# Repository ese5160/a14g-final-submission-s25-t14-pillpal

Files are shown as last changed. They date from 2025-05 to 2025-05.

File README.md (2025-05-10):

Review Assignment Due Date (https://classroom.github.com/a/AlBFWSQg)
# a14g-final-submission

    * Team Number: 14
    * Team Name: PillPal
    * Team Members: Urvi Haval & Suhaila Shankar
    * Github Repository URL: https://github.com/ese5160/a14g-final-submission-s25-t14-pillpal
    * Description of test hardware: (development boards, sensors, actuators, laptop + OS, etc) 

## 1. Video Presentation

https://youtu.be/ZBLSTaz6bz8

## 2. Project Summary
### Device Description  
#### What is our device?   
We have designed and implemented an IoT-based pill dispenser that works using a stepper motor and a custom pill dispensing mechanism, triggered by scheduled commands via Node-RED. It uses a servo for accessing the main compartment with the pills and integrates an RFID module for scure access control. It also uses a temperature sensor to ensure that the device is kept in optimal conditions.   

#### Inspiration  
The project was inspired by the DOTS program for Tuberculosis observed in India that mandates a particular dosage of pills without missing even a single dose. Missing doses can lead to reverse effects. Monitoring this is usually very hard and in a few cases, patients tend to overdose or underdose. Apart from being a regular pill dispenser, we had to make sure that only a doctor or a medical health provider has access to where all the pills are stored to ensure medical adherence.  

#### Internet Integration  
The device connects to the Internet via Wi-Fi and uses MQTT to communicate with a Node-RED dashboard, allowing users or caregivers to remotely monitor, trigger and adjust dispensing schedules in real time.  

### Device Functionality  
#### Overview  
Our pill dispenser is designed around the SAMD21 microcontroller that coordinates inputs from sensors and outputs to actuators, while maintaining two-way communication with a remote server via Wi-Fi. The device ensures secure, scheduled pill dispensing, remote monitoring, and user interaction through a Node-RED dashboard.  
**Key components**:  
SENSORS:  
- RFID Reader (PN532) connected over Arduino which authenticates users before allowing access to refill or interact with the device.  
- Button on the PCB (PB23) used for manual override or triggering functions locally.  
- Temperature sensor (BMP388) periodically logs ambient temperature for monitoring pill storage conditions.  
  
ACTUATORS:  
- Stepper motor (controlled via DRV8834 Driver on board) which rotates the upper disc to align with the correct pill slot with the dispensing outlet.  
-  Servo Motor controls the opening and closing of the main lid for loading pills.  
- Buzzer and LED provide alerts for dispensing confirmation or attention signals.  
  
CONNECTIVITY:  
- Wi-Fi Module which enables MQTT communication between the PCB and the Node-RED dashboard.  
- MQTT Topics:  
1. **"pill/status"**: Used to publish pill dispensing events.  
2. **"pill/count"**: Used to publish remaining pill count.  
3. **"debug/ota"**: Used to download OTAFU through the Node-RED UI.  
  
POWER SUPPLY:  
- The stepper and servo motors are powered by an on-board regulated 5V supply using a boost converter.  
- The rest of the peripherals and the microcontroller are powered by a regulated 3V3 supply from the on-board buck converter.  
  
SOFTWARE INTEGRATION:  
- FreeRTOS manages real-time task scheduling for servo control, stepper rotation, temperature sensor reading and MQTT communication, ensuring deterministic and responsive behavior.  
- The CLI Debug interface allows developers to issue test commands via the serial monitor during development and maintenance.  
  
HARDWARE DESIGN:  
- Our custom PCB was designed using *Altium Designer*. It integrates all components on a compact and efficient layout, with properly routed traces for I2C, motor control signals and regulated power distribution. Going with the theme of the project, we also made the PCB to be a 'plus' sign.  
  
#### System Block Diagram  
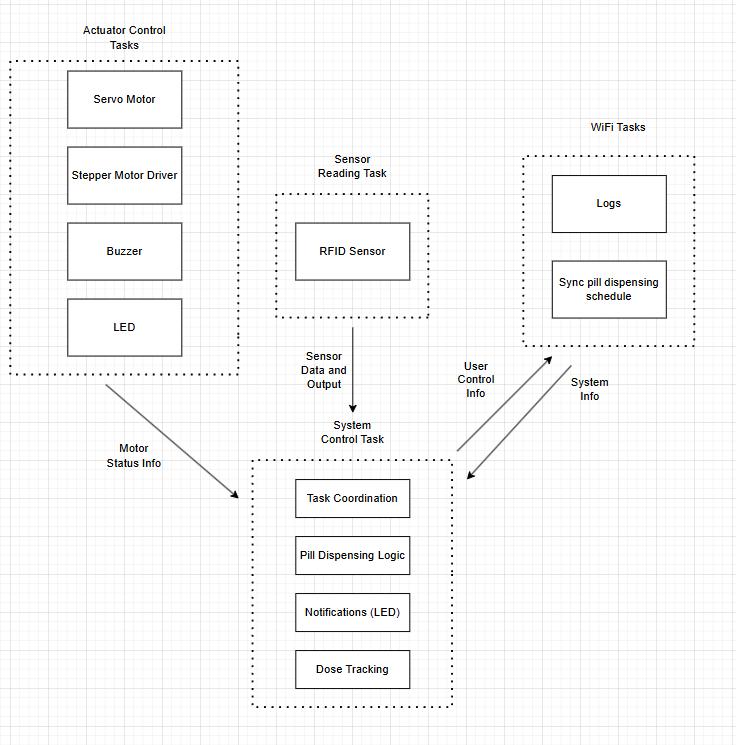
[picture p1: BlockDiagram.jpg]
System Block Diagram

  
### Challenges  
Developing this project involved tackling multiple challenges accross firmware development, hardware debugging and full system integration. Some of the most significant roadblocks and our approaches to resolving them are outlined below.  
  
1. PN532 I2C communication: One of the earliest and most time-consuming challenges in firmware arose during the integration of the PN532 RFID reader via I2C. While writing to the sensor worked reliably using the FreeRTOS-based I2C driver, we consistently missed two packets while reading back from it. We spent quite a lot of time debugging and analyzing on the SALAE Logic Analyzer, tried changing the on-board pull up resistors. Since we were using the breakout board for PN532, the datasheet was not of much help as it was meant for the SOC. The problem was compounded by the lack of thorough documentation or working examples of a minimal I2C-based PN532 driver written in pure C—most open-source implementations either used SPI or were heavily abstracted in C++ (e.g., Adafruit’s Arduino library).  Eventually, in the interest of time and project stability, we decided to offload the RFID functionality to a separate Arduino Nano. This external board successfully communicated with the PN532 using a well-supported library and then forwarded authentication results over UART to the main SAMD21 controller.  

2. Boost Converter Failure: We designed an onboard boost converter circuit using the TPS6123 IC to power certain components from a lower voltage source. However, during early hardware testing, the circuit failed to deliver the expected output voltage. Upon investigation using an electronic load (eload) and multimeter measurements, we discovered that the ground pins on the TPS6123 were inadvertently floating—left electrically unconnected to the board’s main ground plane. To address this, we manually soldered jumper wires to tie the floating ground points to the main ground. Although this initially appeared to resolve the issue, it caused a massive and uncontrolled current draw, ultimately blowing the boost converter. Hence we took the decision to use an external 5V DC supply.  
  
### Prototype Learnings  
Building and testing this prototype provided valuable insights across hardware design, firmware development, and system-level decision-making. Through iterative development and troubleshooting, we identified both best practices and areas for improvement.  
**Key Lessons Learnt:**  
1. While the PN532 RFID module offered robust features, its complexity and lack of C-based I2C documentation slowed our progress significantly. In hindsight, choosing a simpler RFID reader or integrating the module directly onto the PCB instead of using a breakout board would have reduced wiring errors, saved space, and improved stability.  
2. During FreeRTOS integration, we initially underestimated the memory requirements for tasks like Wi-Fi, I2C, and servo control. These tasks, especially when using semaphores and queues, require careful tuning of stack sizes and heap allocation. We learned to regularly monitor uxTaskGetStackHighWaterMark() and adjust configTOTAL_HEAP_SIZE early in development to prevent obscure runtime crashes.  
3. One of the most important takeaways was learning when to stop pursuing a dead-end and shift to a viable workaround. Rather than getting stuck debugging low-level I2C read issues with the PN532, we made the decision to offload the RFID task to a dedicated Arduino. This pivot allowed us to maintain progress and demonstrated the value of modular, flexible architecture in embedded design.  

**What we'd do differently**:  
- Opt for a simpler or more well-documented RFID solution with native MCU support and potentially integrate it directly into the custom PCB.  
- Allocate more time early on for testing task stack sizes and overall heap usage to avoid late-stage integration issues.  
- Prioritize pragmatic engineering and spending less time on unsolved problems and being quicker to adopt alternate paths when necessary.  

### Next steps and takeaways  
#### Next steps to improve the project  
1. **Enhancing the Node-RED dashboard**: The current UI supports basic control, but it can be made far more interactive. Future improvements include adding pill scheduling via a software-based RTC, supporting multiple daily dispensing times, and dynamically updating the remaining pill count. Enhancing the interface with custom CSS would also improve usability and accessibility.  
2. **Simplifying RFID hardware integration**: Instead of relying on a bulky breakout board and an Arduino for RFID handling, future iterations could include a simpler I2C-compatible RFID module (like the SparkFun Qwiic RFID) that can be directly integrated into the main PCB. This reduces wiring complexity, power consumption, and form factor.  
3. **Refining task synchronization and System Integration**: While the prototype runs all subsystems, better task coordination using semaphores better (e.g., signaling between the button, servo, and stepper tasks) would make the system more efficient and deterministic under FreeRTOS. A more structured communication scheme would also reduce the likelihood of task starvation or conflicts.
  
#### What we learned during ESE5160   
Throughout the ESE5160 course, we gained practical and theoretical skills essential to embedded system development.  
1. Firmware Design and RTOS Concepts: We learned how to structure embedded applications using FreeRTOS, manage concurrency using tasks, queues, and semaphores, and debug common issues like stack overflows and heap exhaustion.  
2. Peripheral and Driver Integration: Assignments and lectures taught us how to interface with hardware components such as LEDs, servos, buttons, I2C sensors, and motor drivers through low-level drivers and interrupt-safe communication patterns.  
3. Networking and IoT Protocols: Implementing MQTT and integrating with a cloud-based Node-RED dashboard taught us how to design real-world IoT applications involving secure data exchange and remote control.  
4. System-Level Debugging and Design Thinking: Most importantly, we learned how to debug complex hardware-software interactions and make trade-offs between ideal and practical solutions, especially during our prototype’s challenges.  

### Project Links  
**Link to Node-RED instance:** http://135.119.168.251:1880/ui/#!/1?socketid=zufB0bCCymFWlRAdAAC7  
**Link to PCBA:** https://upenn-eselabs.365.altium.com/designs/8B70E409-2835-43B1-999B-2FA11EA3B7DD#design

## 3. Hardware & Software Requirements  
### Hardware Requirements Validation

| ID | Requirement Description | Status | Validation Method |
|---|---|---|---|
| HR 01 | Project uses the SAMW25 microcontroller module |  Met | Verified via firmware check / chip ID. |
| HR 02 | An RFID reader shall be used for access control. The reader shall authenticate RFID tags at a maximum distance of 5 cm and communicate with the microcontroller via I2C. |  Partially Met | Range tested with ruler. Communication verified via I2C ACK/NACK and tag UID. |
|HR 03 | If the RFID tag matches the reader, the main compartment shall open, which is controlled by a servo motor. | Met | The servo opens and closes the slot for inputting the pills.
| HR 04 | The pill will be dispensed using a carousel design. A rotating disc is aligned with a dispensing chute. The disc rotates using a stepper motor to position the correct slot over the chute at the scheduled time. | Met | Tic-Tac placed for experimenting is dispensed. |
| HR 05 | The device shall include a buzzer for audio notifications. The buzzer shall produce a sound output of at least dB at ? cm and shall be activated for dose alerts. |  Partially Met | Buzzer tested. dB output needs measurement at 10 cm using phone dB meter. |
| HR 06 | A Lithium Ion Cylindrical Battery - 3.7V, 2200mAh shall be used as the power source. The battery shall be parallely connected to a Boost Convert (6V) and a Buck Converter (3.3V). |  Partially Met | Multimeter used to verify 3.3V rail. Performed e-load testing as well. Boost converter however does not work due to DRC errors in the PCB design. Used an external 5V DC supply. |
| HR 07 | The enclosure and carousel dispensing mechanism should be 3D printed. |  Met | Measured dimensions. Lid and mechanism assembled as per spec. |
| HR 08 | The pill dispenser shall use 802.11 b/g/n Wi-Fi for communication with cloud services. |  Met | Verified MQTT communication with Node-RED via serial logs. |
| HR 09 |  An LED shall indicate dose alerts. |  Met | LEDs trigger on stepper motor turning battery logic. |
| HR 10 | A load cell/force sensor should be placed at the end of the dispenser to check if the patient picks up the pill |  Not Met | Was not a mandatory requirement. |

### Software Requirements Validation  
## Software Requirements Validation

| ID | Requirement Description | Status | Validation Method |
|---|---|---|---|
| SRS 01 | A notification shall be sent to the patient when they need to take their medication on Node-RED. |  Met | Verified on Node-RED task. |
| SRS 02 | A reminder notification shall be sent in 5 minutes if the patient has not taken their medication. | Not Met | Future scope |
| SRS 03 | A counter shall keep track of the number of pills left in the dispenser and alert the patient. The counter subtracts the pill amount every time the stepper motor dispenses the pill. |  Met | Decrement logic on stepper task; MQTT alert sent. Verified on Node-RED |
| SRS 04 | A schedule shall be set by the provider to send reminders for taking pills. | Partially Met | Practitioner can set schedule on Node-RED dashboard. Future scope to integrate it with the hardware. |
| SRS 05 | An MQTT broker shall communicate with Node-RED for sending alerts |  Met | Verified with payloads on "pill/alert" and "pill/status" topics. |
| SRS 06 | Node-RED UI dashboard shall displays pill count, status, and connectivity |  Met | Dashboard fields update on MQTT publish from MCU. | 
| SRS 07 | A FreeRTOS task shall read temperature data every 10 seconds and publish it via MQTT |  Met | Temperature task uses vTaskDelay(10000/portTICK_PERIOD_MS). MQTT publish verified on topic "pill/temp". Reading accuracy validated by comparing with ambient temperature. |
| SRS 08 | The system shall run all tasks (dispense, sensor, comms, alerts) concurrently under FreeRTOS |  Partially Met | Tasks are created and run under FreeRTOS. Validation via serial logs and functional testing. However, system occasionally freezes or stops responding, indicating potential stack/heap mismanagement or race condition. Debugging ongoing. |

## 4. Project Photos & Screenshots

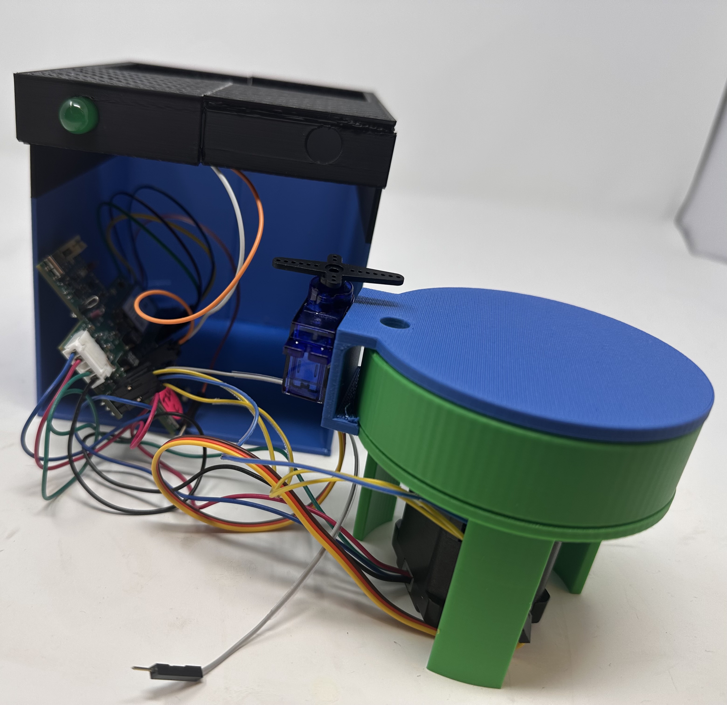
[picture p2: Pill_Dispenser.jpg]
Dispenser


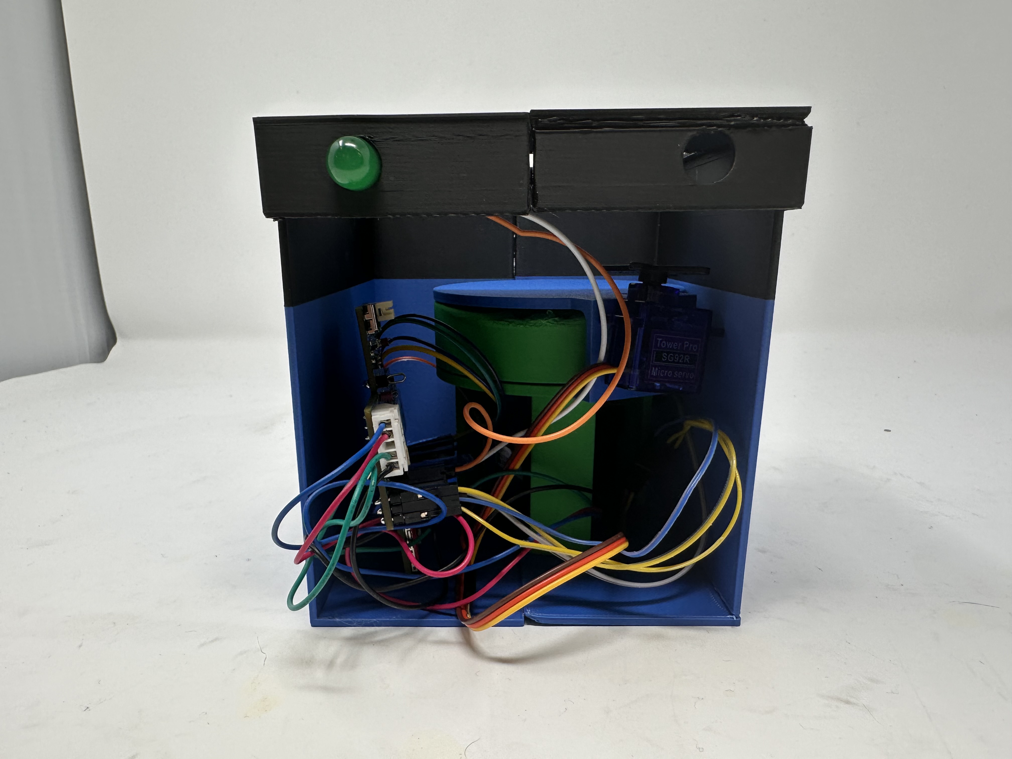
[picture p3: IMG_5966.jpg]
Setup


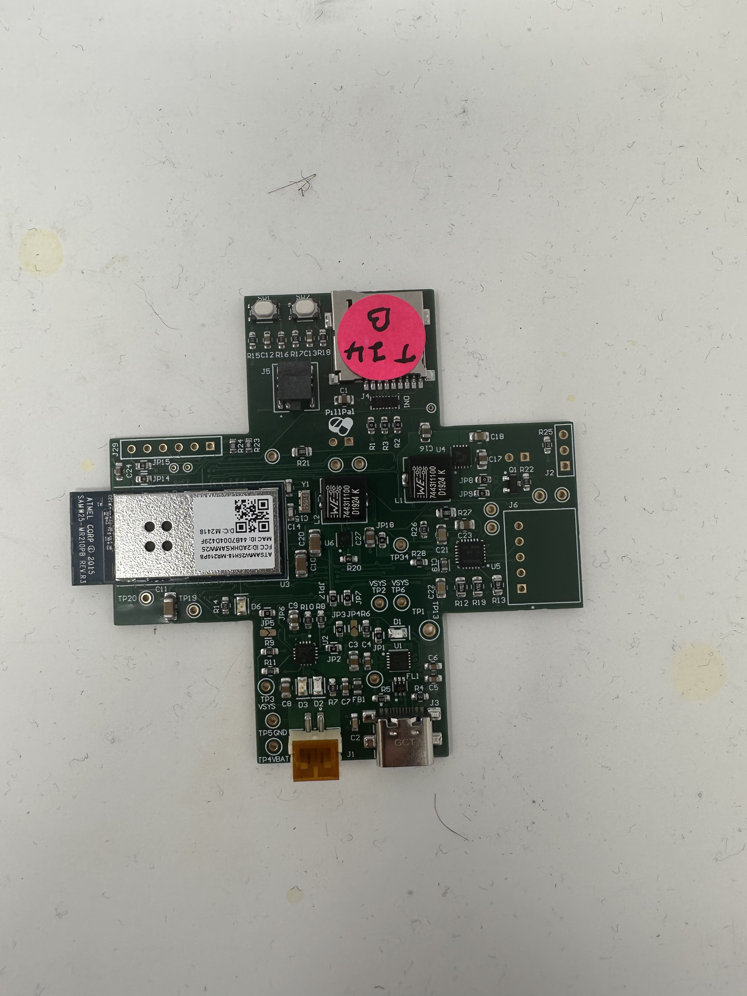
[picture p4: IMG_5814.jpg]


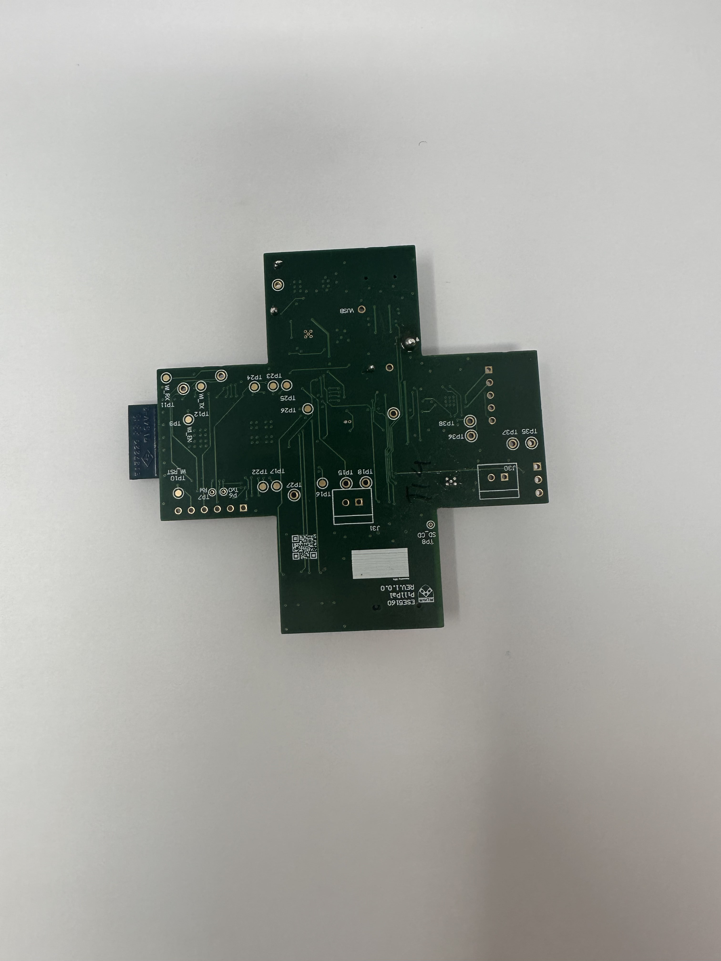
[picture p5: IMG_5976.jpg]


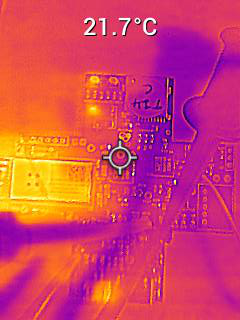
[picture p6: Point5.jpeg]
Thermal Camera


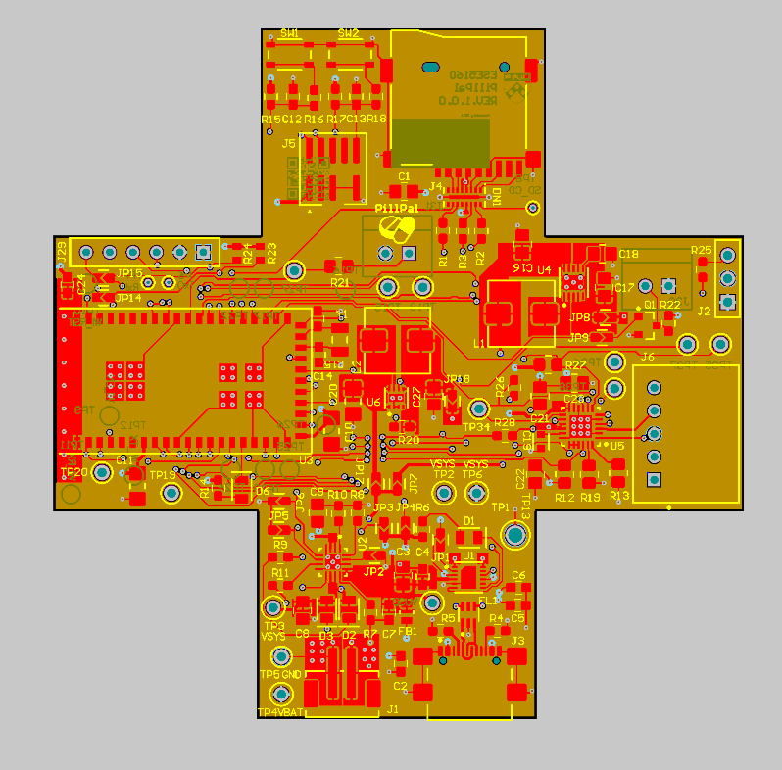
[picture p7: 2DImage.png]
2D Image


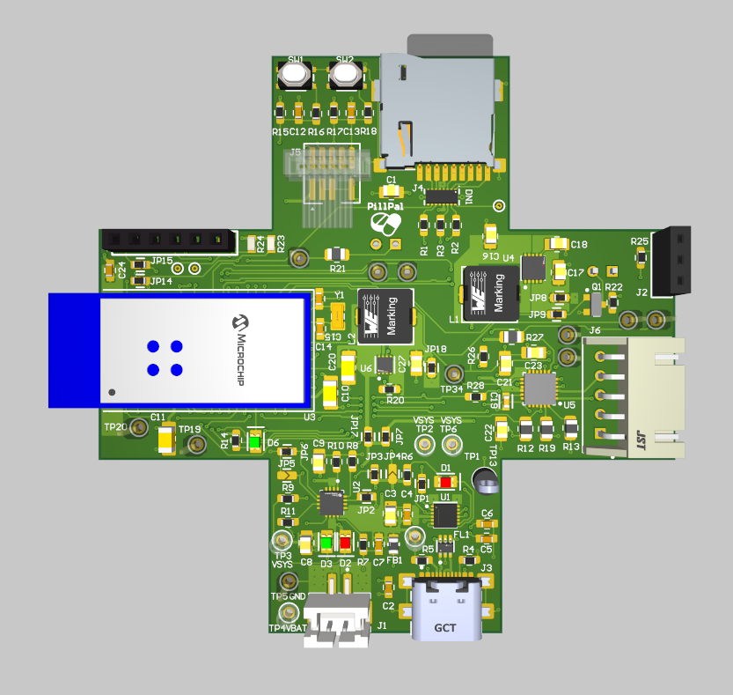
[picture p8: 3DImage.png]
3D Image


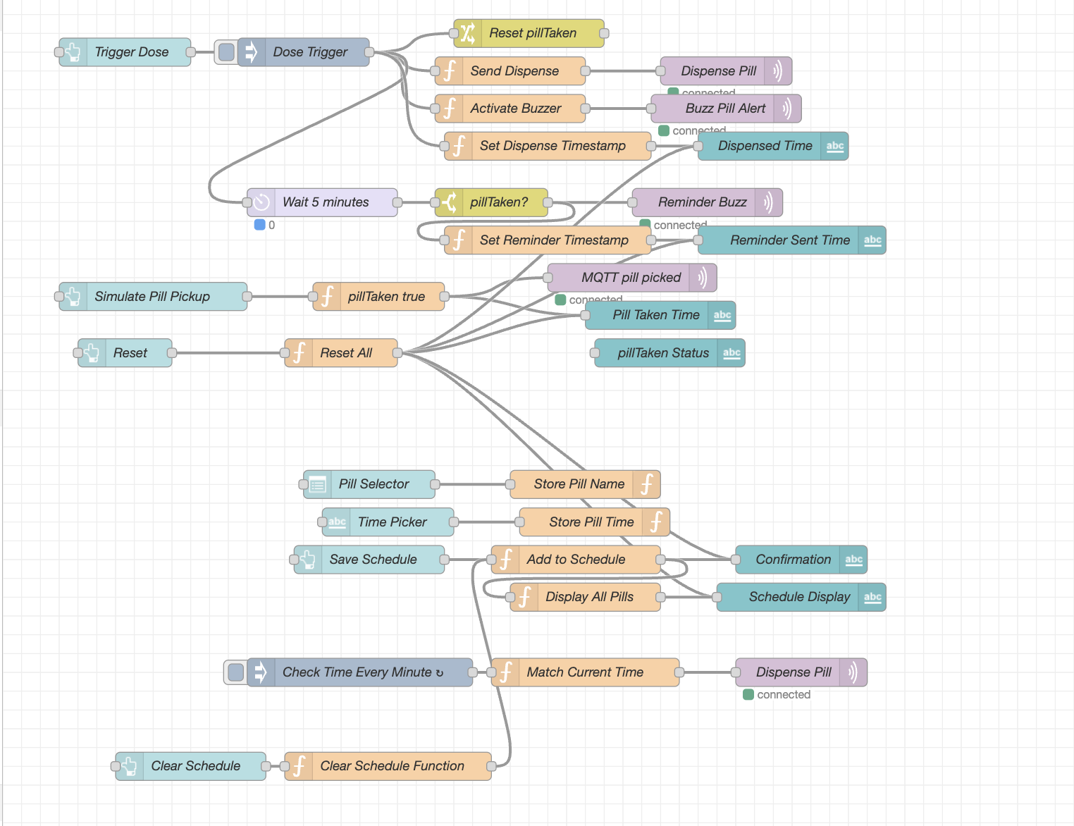
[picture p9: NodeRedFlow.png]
Node Red Flow


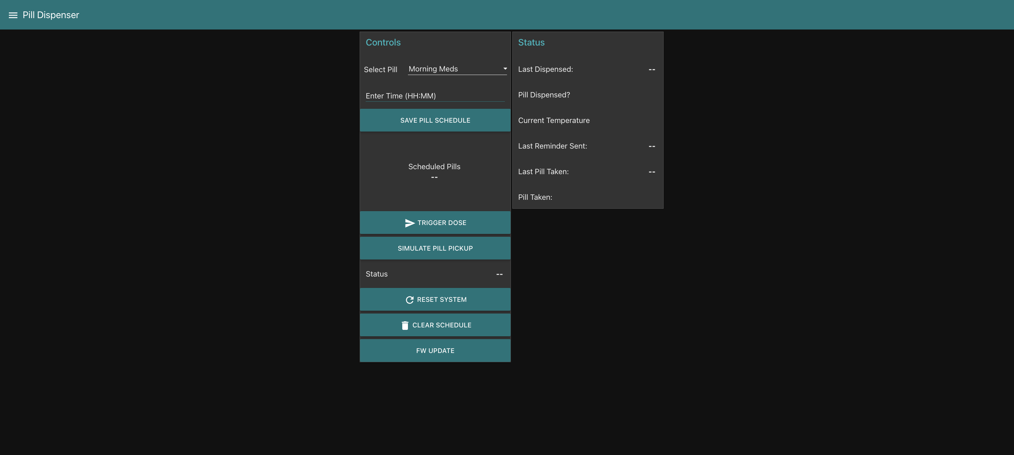
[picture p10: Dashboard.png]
Dashboard


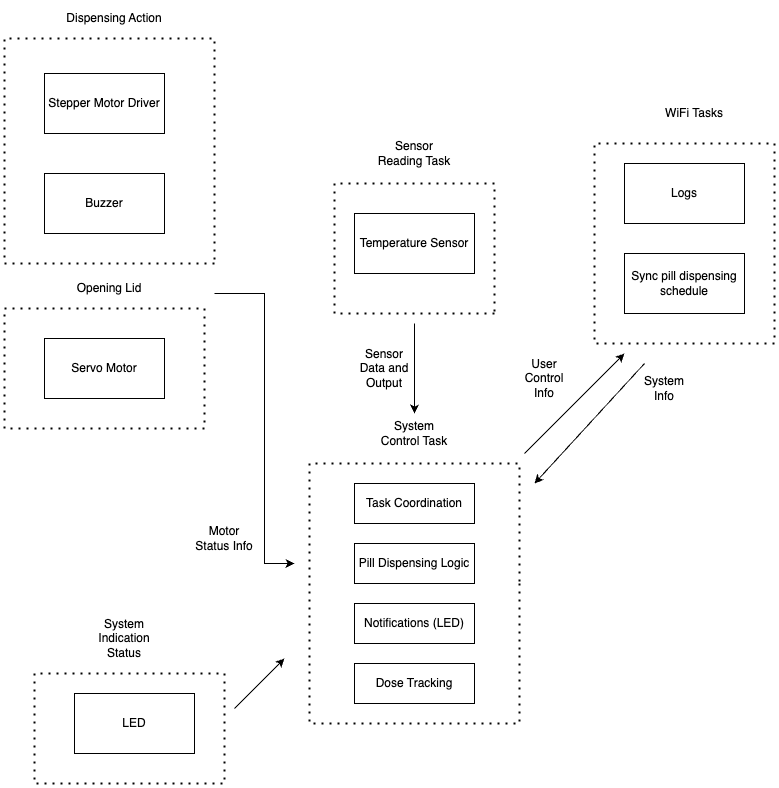
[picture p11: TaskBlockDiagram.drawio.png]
Block Diagram


## Codebase

- A link to your final embedded C firmware codebases: Github
- A link to your Node-RED dashboard code: 
- Links to any other software required for the functionality of your device

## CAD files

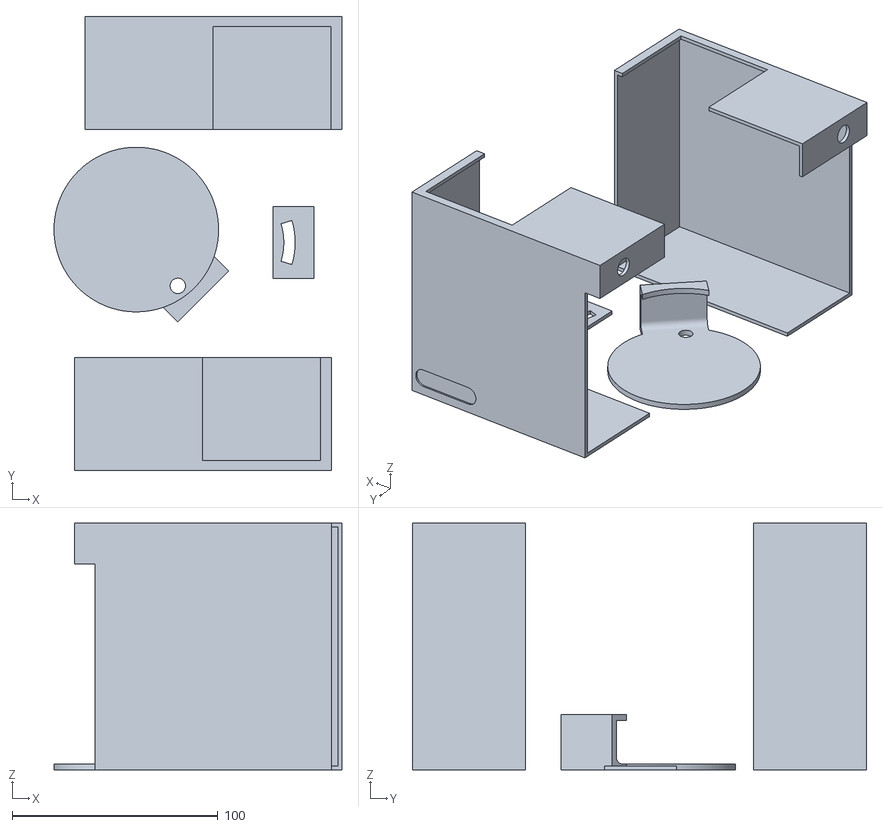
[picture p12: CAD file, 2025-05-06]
mcad/DeviceEnclosure.stl
139.9 x 220.8 x 120.0

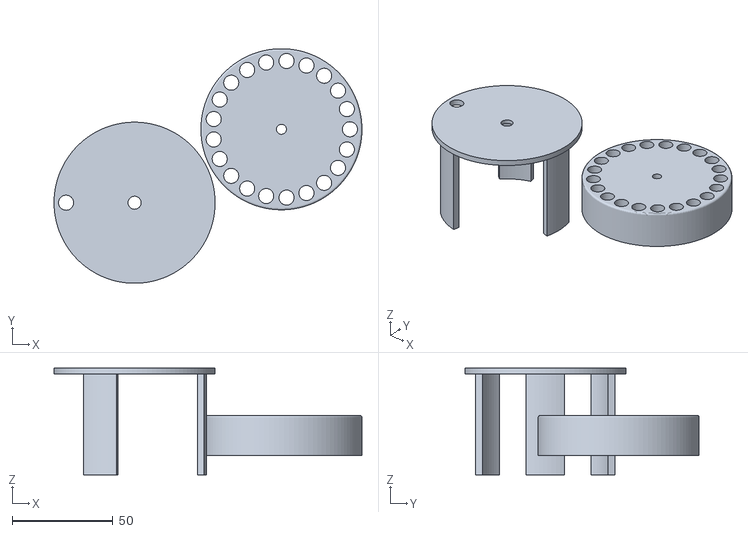
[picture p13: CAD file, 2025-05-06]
mcad/Dispensingmechanism.stl
152.9 x 116.4 x 53.0
